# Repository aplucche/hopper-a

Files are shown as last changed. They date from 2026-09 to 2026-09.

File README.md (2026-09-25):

# HOPPER-A — rubber-band jumping toy (42 mm cube, PLA + rubber bands only)

***Note on LLM Usage***: *All code and documentation after this section is fully generated. This is a test of Opus 5.5 with Claude Code for physical design. The unmodified prompt is below (created on mobile so excuse some poor grammar and typos). All development was done in a Claude Code cloud env.*

***One-shot prompt***:
> Can you make an openscad file with all components laid out in a printable manner as well as a toggle-able view of an assembled version for an A1 mini bambu printer. The project: a hopper toy with only PLA and rubber bands that had an easy way to release without getting in the way. must be completely enclosable in 42mm cubed dimensions.  
Goals are jumps n feet in the air with only parts specified and m rubber bands. Can withstand tension of specified number of bands without plastic breaking.  
I will be unavailable so please act autonomously and with as high a quality end result as possible. Autonomously use version control along the way.

**Video of assembled device in action:**

https://github.com/user-attachments/assets/377958ef-da96-43a3-9e8f-0fc779bee860

---
-- Generated --
# HOPPER-A — rubber-band jumping toy (42 mm cube, PLA + rubber bands only)

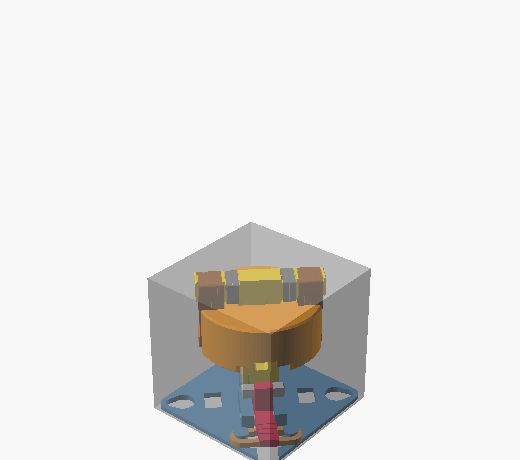
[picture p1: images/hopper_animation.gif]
animation


A 3D-printable jumping toy for the **Bambu Lab A1 mini**. It's made from PLA and standard **#8 rubber bands** and nothing else: no screws, springs or glue.
The whole toy, bands included, fits inside a **42 × 42 × 42 mm cube** (measured: 41.7 × 41.7 × 41.6 mm).

| | 2 bands (1 per side) | **4 bands (2 per side) — recommended** | 6 bands (3 per side) — limit |
|---|---|---|---|
| predicted jump (nominal) | 3.0 ft (0.9 m) | **5.6 ft (1.7 m)** | 8.0 ft (2.4 m) |
| realistic range (soft … stiff bands) | 1.8 – 4.4 ft | **3.5 – 8.1 ft** | 5.1 – 11.4 ft |
| force to cock (push the body down) | 25 N (2.6 kgf) | 50 N (5.2 kgf) | 76 N (7.7 kgf) |
| pedal force to fire | ≈3 N | ≈5 N | ≈7 N |
| lowest static safety factor on the PLA | 6.2 | **3.1** | 2.1 |
| lowest impact safety factor (pessimistic) | 3.5 | **2.5** | 2.0 |

**Goal statement.** With only the printed parts and **4 × #8 rubber bands** (each looped double), the toy jumps
**about 5½ ft (1.7 m) straight up**. Every PLA part keeps a **safety factor of 3 or more** when cocked with those
4 bands, and still **2 or more at 6 bands**. The full numbers are in [docs/PERFORMANCE.md](docs/PERFORMANCE.md).
The jump heights come from a physics model. Real rubber bands vary a lot, so expect your toy to land somewhere in the range column.

Also needed: **1 more #8 band** for the trigger return spring and **2 more** for the crossbar bumpers.
That's **7 × #8 bands** in total for the recommended build.

## How it works

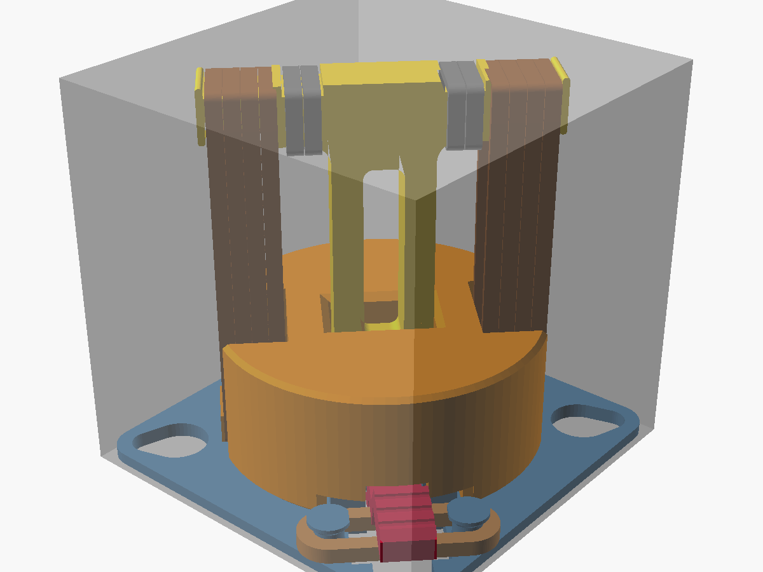
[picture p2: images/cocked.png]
cocked


* **Foot** (blue): the base plate. It holds the central boss and the pivot block.
* **Frame** (gold): a "T" made of a stem and a crossbar. It's printed lying flat, so every tensile load runs along the filament. It pins into the foot from underneath.
* **Body** (orange): a 7.3 g puck that slides on the stem. Its mass is tuned to match the 7.1 g foot side, because a 1:1 split maximises jump height for a given amount of band energy.
* **Bands**: they loop over the crossbar ends and under pegs at the bottom of the body. Pushing the body *down* stretches them to about 3.9× their length.
* **Latch**: a pedal lever sits in the foot. Its steel-grey **sear pin** hooks over two barbs that hang inside the body.
  * **Cocking:** push the body down. The barbs cam the pin aside and it clicks in (18.6 mm stroke).
  * **Firing:** tap the **corner pedal down**. After about 13° of rotation (≈3 mm of pedal travel) the pin slips off the barbs. The body shoots up at about 12 m/s, hits the rubber-cushioned crossbar, and yanks the whole toy off the table.
  * **Why the pedal stays out of the way:**
    * It sits at the foot corner, outside the body's path.
    * You press it *down*, so the toy can't be pushed sideways across the table.
    * After release the lever can keep swinging for another 45°+. A finger still resting on the pedal therefore can't hold the foot down. The foot just pulls the pedal out from under the finger.
  * **Return spring:** a doubled #8 band stretched between two pegs like a bow-string, under the pedal arm.

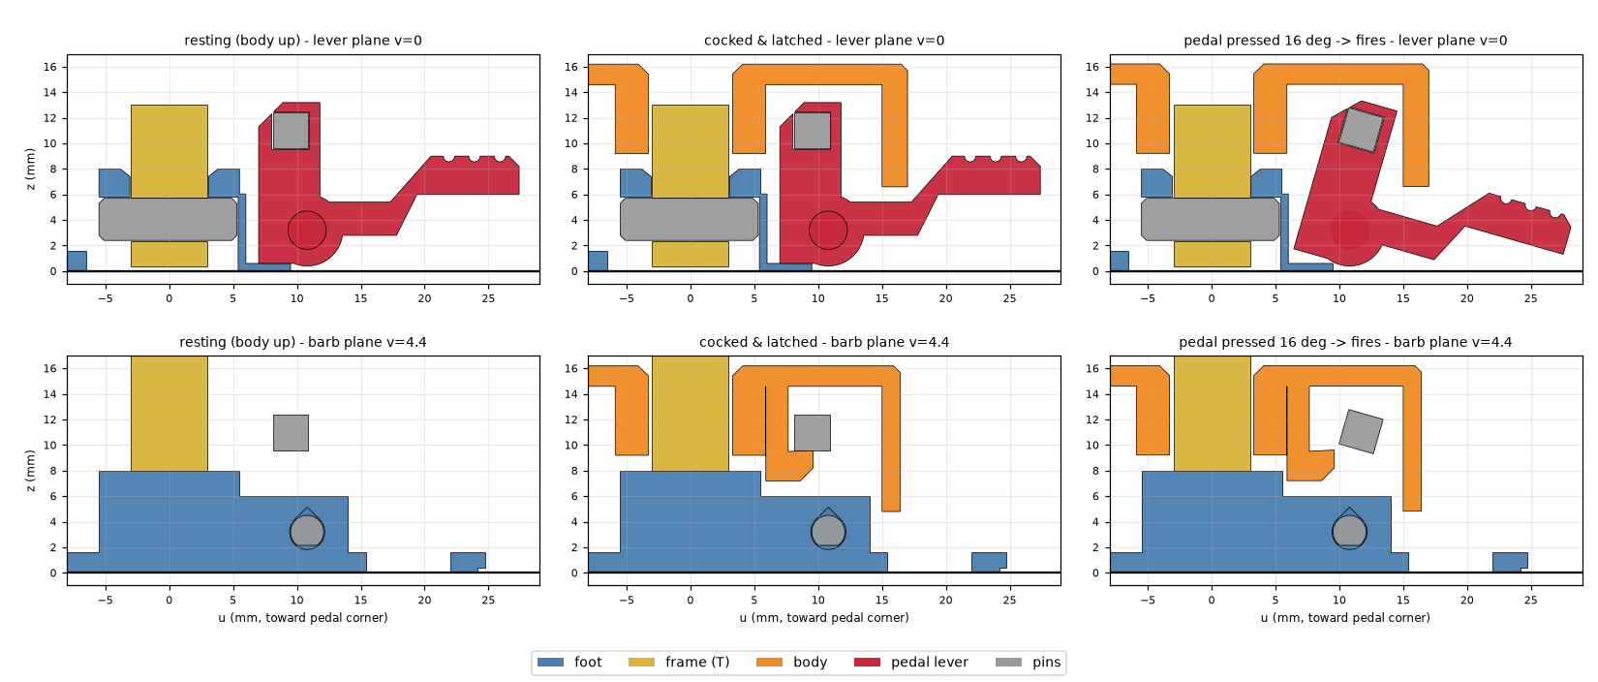
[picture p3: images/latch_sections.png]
latch sections


## Files

| file | what |
|---|---|
| `hopper.scad` | The fully parametric model. Open it in OpenSCAD and use the **Customizer** `view` drop-down to switch between the views below. |
| `stl/hopper_plate.3mf` | **All 10 parts laid out for the A1 mini plate, as separate objects.** Open it directly in Bambu Studio. |
| `stl/hopper_*.stl` | One STL per part, already in print orientation. `hopper_plate.stl` is the whole plate as a single mesh. |
| `docs/PERFORMANCE.md` | Generated report: stretch, forces, energy, jump height, trigger force, and a safety factor for every load path. |
| `docs/BUILD.md` | Printing, assembly, use and tuning. |
| `tools/` | Checks and generators (see below). |

### Views in `hopper.scad` (Customizer → View → `view`)

| `view` | shows |
|---|---|
| `assembled` | resting toy inside the transparent 42 mm envelope cube (default) |
| `cocked` | body pulled down and latched |
| `firing` | pedal pressed and sear released |
| `exploded` | assembly pulled apart vertically |
| `section` | cocked toy cut on the lever mid-plane |
| `animate` | cock → fire → jump; use View ▸ Animate (FPS 15, Steps 120) |
| `print` | every part on the 180 × 180 A1 mini bed |
| `part` | one part (choose it in `part`) in print orientation, for STL export |

Other toggles: `show_bands`, `show_envelope`, `show_bed`, `bands_per_side` (1–3, visual only).
Print fits (`fit_slide`, `fit_rot`, `fit_pin`) and latch tuning (`e_bias`, `barb_tilt`, `overtravel`) are Customizer parameters too.

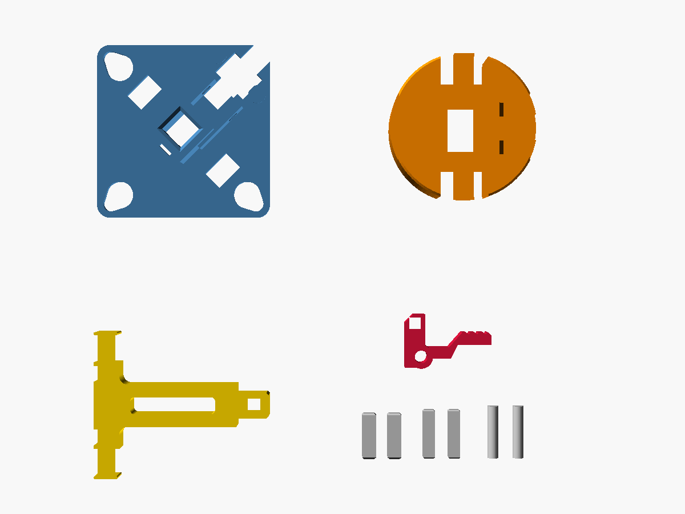
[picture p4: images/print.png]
print plate


## Verification (`tools/build_all.sh`)

The tools rebuild and re-check everything after any edit:

* **`check_geometry.py`** runs exact mesh booleans (manifold3d) on every part and checks:
  * every part is a closed solid
  * no two parts overlap at rest, latched or bottomed out
  * the latch cocks correctly at every body height, and the lever deflection needed on the way down is recorded
  * the sear releases at 13° of rotation
  * the lever swings freely for at least 45° after release
  * the assembled toy, bands included, fits inside 42 mm
  * the body's centre of mass sits on the stem axis (0.13 mm off)
  * it also records each part's mass
* **`hopper_calc.py`** runs the neo-Hookean rubber model, the launch and drag model, the trigger and friction model, and the stress checks. It writes `docs/PERFORMANCE.md`.
* **`section_plot.py`** draws the latch cross-sections from the real meshes.
* **`export_stl.py`** writes the STLs and the 3MF, then checks that the plate holds 10 separate bodies, all on the bed and all inside 180 mm.

Requirements: `openscad` (2021.01 or newer), `xvfb-run` for images, and Python 3 with `trimesh manifold3d shapely scipy matplotlib lxml`.

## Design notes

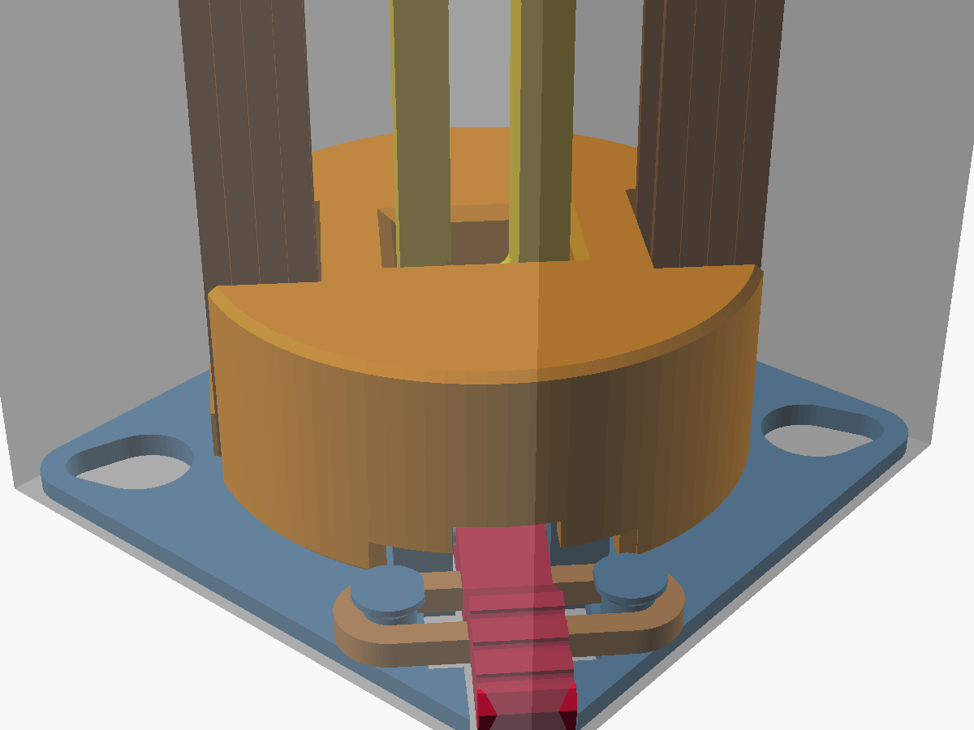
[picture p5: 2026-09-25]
images/firing.png

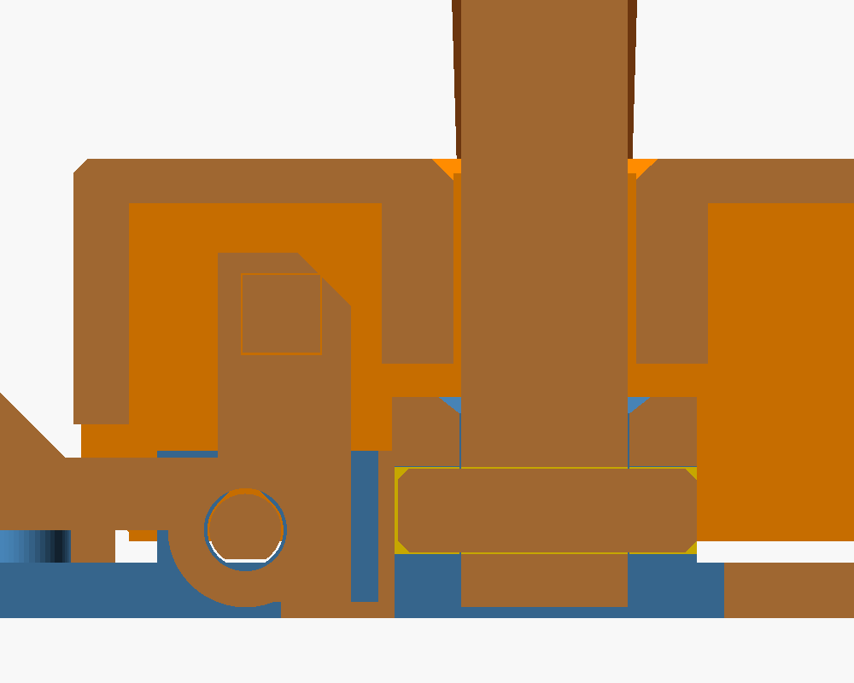
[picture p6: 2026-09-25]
images/section.png

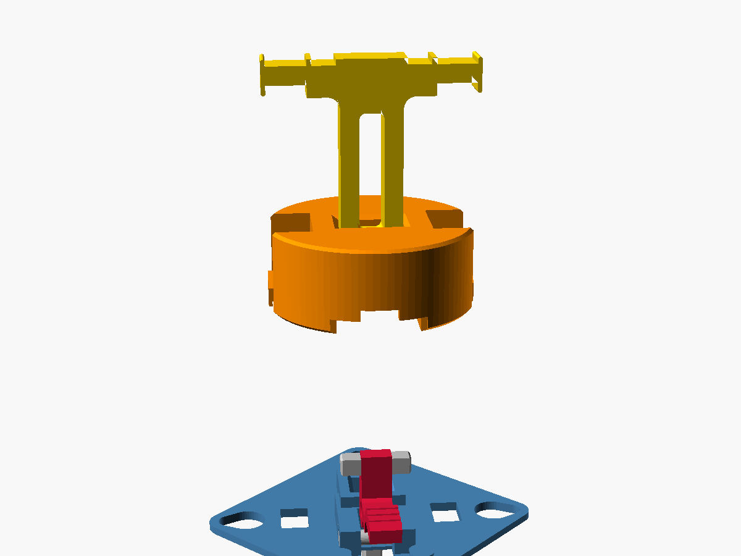
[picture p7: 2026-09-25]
images/exploded.png

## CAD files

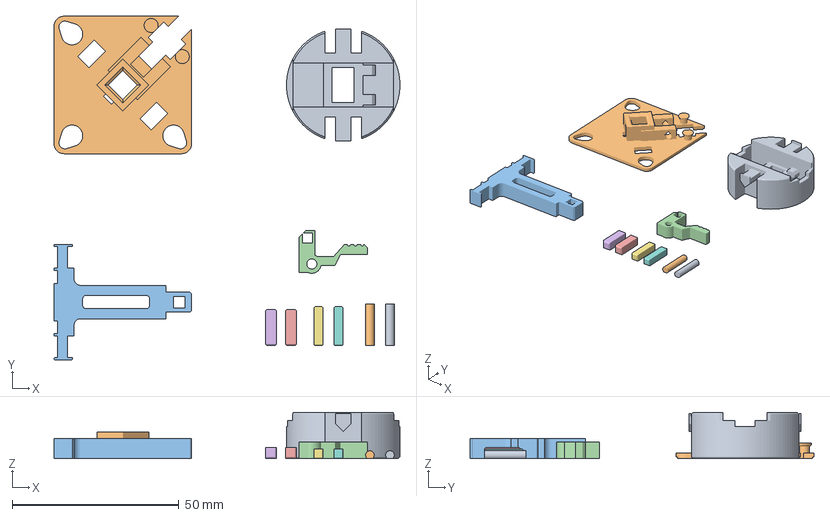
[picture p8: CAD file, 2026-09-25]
stl/hopper_plate.3mf
103.6 x 102.9 x 13.8 mm

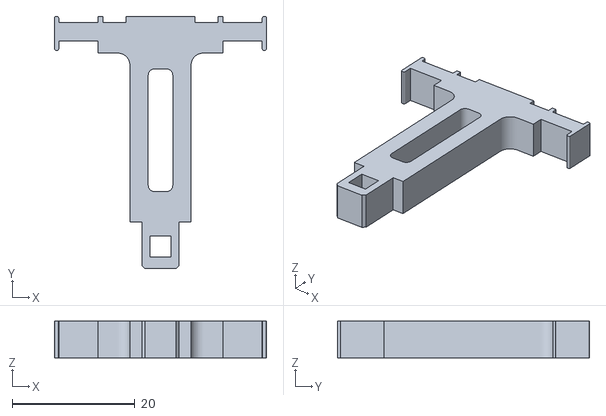
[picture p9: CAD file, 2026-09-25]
stl/hopper_frame.stl
34.6 x 41.2 x 6.00

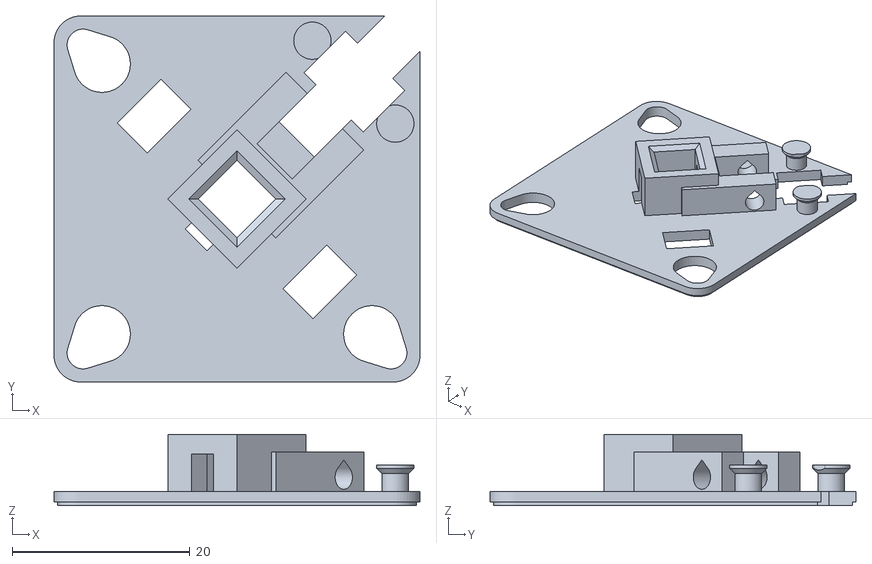
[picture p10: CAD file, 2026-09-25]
stl/hopper_foot.stl
41.2 x 41.2 x 8.00

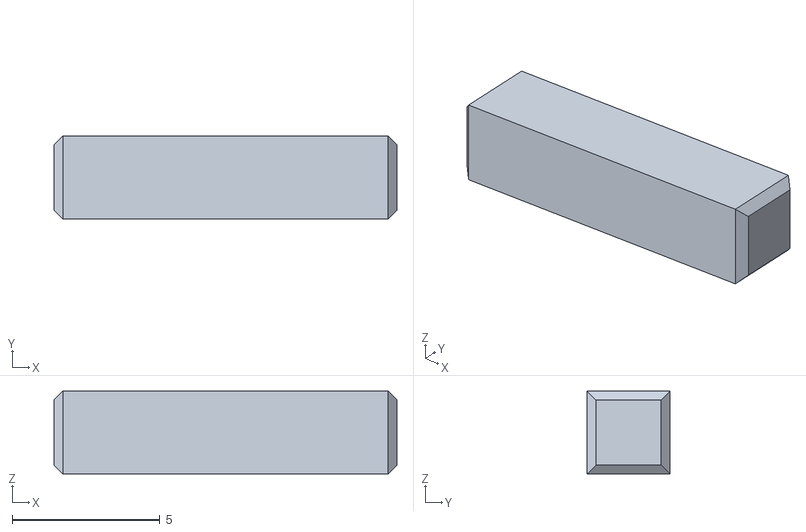
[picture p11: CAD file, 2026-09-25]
stl/hopper_sear_pin.stl
11.6 x 2.80 x 2.80

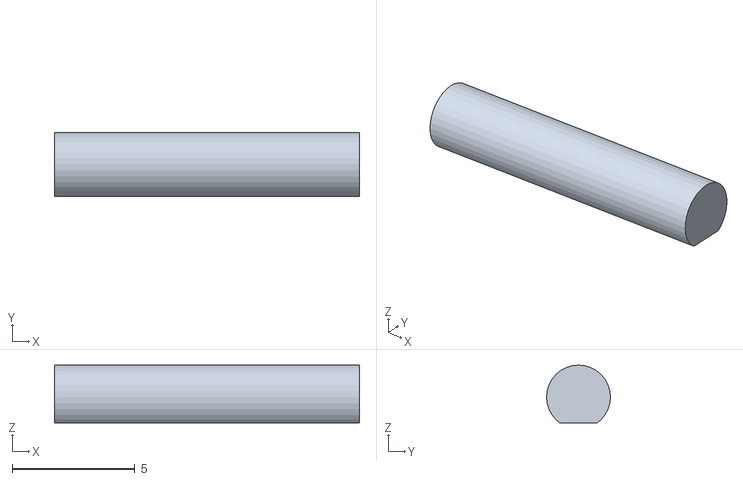
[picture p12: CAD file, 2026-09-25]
stl/hopper_pivot_pin.stl
12.4 x 2.60 x 2.35

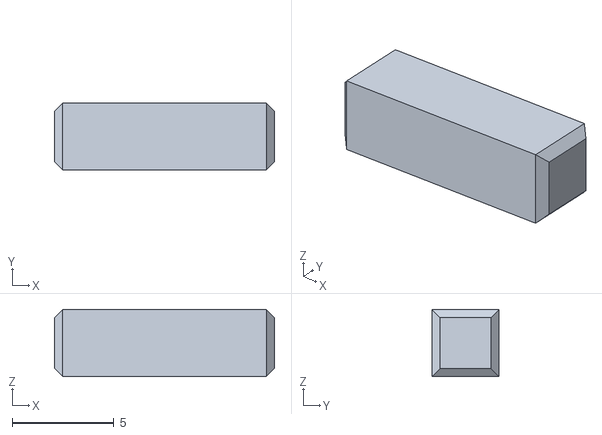
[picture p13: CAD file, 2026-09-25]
stl/hopper_stem_pin.stl
10.8 x 3.30 x 3.30

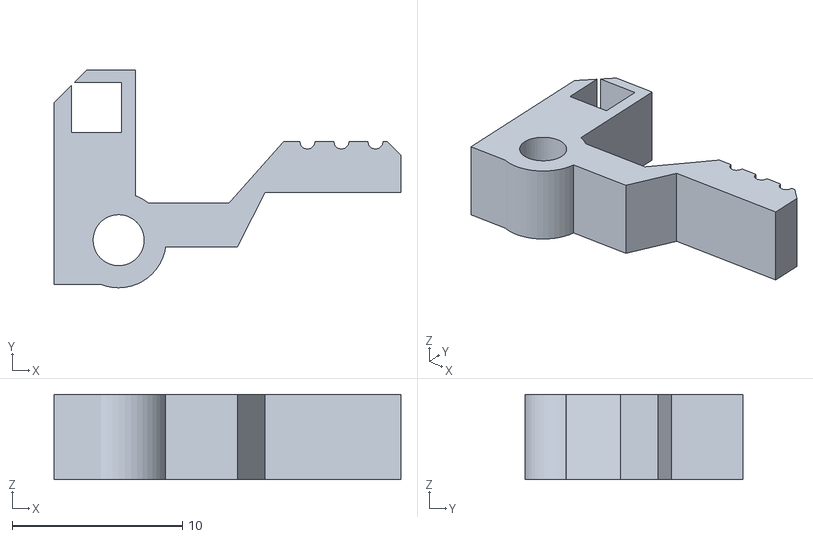
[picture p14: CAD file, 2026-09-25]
stl/hopper_lever.stl
20.4 x 12.8 x 5.00

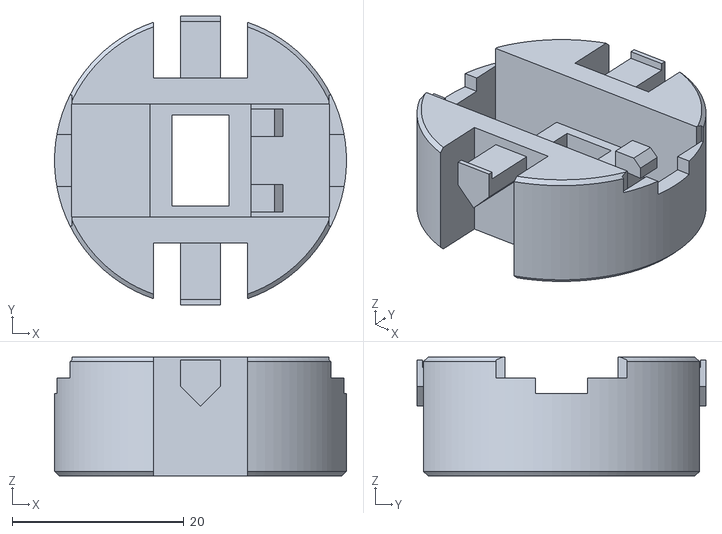
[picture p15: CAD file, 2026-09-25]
stl/hopper_body.stl
34.0 x 33.6 x 13.8

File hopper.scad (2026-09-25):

// =====================================================================
//  HOPPER-A  :  rubber-band jumping toy, 42 mm cube envelope
//  PLA + standard #8 rubber bands only.  Designed for Bambu Lab A1 mini.
//
//  How it works
//  ------------
//  * FOOT  : a base plate with a central boss and a pivot block.
//  * FRAME : a "T" (stem + crossbar) pinned into the foot. Printed lying
//            flat so every tensile load runs along the filament.
//  * BODY  : a heavy puck that slides on the stem.
//  * BANDS : loop over the crossbar ends and under pegs at the bottom of
//            the body, so pushing the body DOWN stretches them.
//  * LATCH : a pedal lever in the foot. Its sear pin hooks over two barbs
//            on the body. Push the body down -> it clicks. Tap the corner
//            pedal DOWN -> the pin slips off the barbs -> the body shoots up,
//            slams the crossbar and yanks the whole toy into the air.
//            The pedal is at the corner, outside the body's path, and the
//            lever keeps rotating freely after release, so a finger on
//            the pedal cannot hold the foot down.
//
//  Views (Customizer "view"):
//    assembled  - resting state (bands relaxed)          [default]
//    cocked     - body pulled down and latched
//    firing     - pedal pressed, sear released
//    exploded   - assembly exploded along Z
//    section    - cocked state cut on the lever mid-plane
//    animate    - use View > Animate (FPS 15, Steps 120)
//    print      - all parts laid out on the 180x180 A1-mini plate
//    part       - a single part (set "part") in print orientation
//
//  Units: mm. Mechanism frame: X = lever axis (u), Y = crossbar axis (v).
//  The assembled views are rotated -45 deg so the square foot is aligned
//  with the world axes and the 42 mm envelope cube.
// =====================================================================

/* [View] */
view = "assembled"; // [assembled, cocked, firing, exploded, section, animate, print, part, info]
part = "foot";      // [foot, body, frame, lever, stem_pin, pivot_pin, sear_pin]
show_bands = true;
show_envelope = true;
show_bed = true;
bands_per_side = 2; // [1, 2, 3]

/* [Fit tuning (mm)] */
fit_slide = 0.30;   // body bore clearance per side on the stem
fit_rot   = 0.40;   // diametral clearance of lever on pivot pin
fit_pin   = 0.15;   // diametral clearance for press-in pins (holes are +this)
fit_gap   = 0.40;   // general non-contact clearance

/* [Latch tuning] */
e_bias    = 1.2;    // pivot offset beyond barb edge; bigger = lighter trigger
barb_tilt = 3;      // deg; barb face rises toward the lever (adds hold)
overtravel = 0.8;   // how far past the latch point the body must be pushed

/* [Hidden] */
$fn = 48;
eps = 0.01;

// ---------------- envelope ----------------
env        = 42;
env_margin = 0.4;
top_z      = env - env_margin;          // 41.6 top of crossbar
foot_side  = env - 2*env_margin;        // 41.2 square foot
foot_cr    = 3;                         // foot corner radius

// ---------------- foot ----------------
t_plate  = 1.6;
boss_h   = 5.5;      // half size of central boss
boss_top = 8.0;
ten_h    = 3.0;      // tenon half size (u & v)
ten_z0   = 0.4;
spin     = 3.3;      // stem pin section (square)
spin_z0  = 2.4;
spin_u0  = -boss_h;  // pin runs from here...
spin_len = 10.8;     // ...for this long (+u end stops in the groove)

// ---------------- lever / pivot ----------------
pv_d       = 2.6;                         // pivot pin diameter
lev_boss_r = (pv_d + fit_rot)/2 + 1.3;
lev_min_z  = 0.4;
z_p        = lev_min_z + lev_boss_r;      // pivot height
blk_top    = z_p + (pv_d + fit_pin)/2*sqrt(2) + 0.9;  // teardrop apex + wall
blk_v      = 6.2;                         // pivot block half width
blk_u1     = 14.0;                        // pivot block end
slot_v     = 2.8;                         // lever slot half width
lw         = 5.0;                         // lever thickness
slot_u0    = 6.0;
slot_floor_z  = 0.6;                      // lever rest stop (tail sits here)
slot_floor_u1 = 9.5;

// ---------------- sear geometry ----------------
z_b_min   = t_plate;                      // body bottoms on the plate
z_b_latch = z_b_min + overtravel;
prong_u0  = boss_h + fit_gap;             // 5.9
prong_v0  = slot_v;                       // 2.8
prong_v1  = 6.0;
pr_bot_rel   = blk_top + 0.35 - z_b_min;  // prong bottom above body bottom
barb_h       = 2.4;
barb_top_rel = pr_bot_rel + barb_h;       // barb edge height (body frame)
u_f       = 9.6;                          // barb +u face
ov        = 1.5;                          // sear overlap
sear_clr  = 0.45;
step_u    = u_f - ov - sear_clr;          // prong face above the barb
z_c       = z_b_latch + barb_top_rel;     // contact height when latched
u_p       = u_f + e_bias;                 // pivot position
lp        = 2.8;                          // sear pin section (square)
lp_u0     = u_f - ov;                     // sear pin -u face
lp_len    = 2*(prong_v1 - 0.2);           // 11.6
head_wall = 0.8;
head_u0   = lp_u0 - head_wall;
head_u1   = lp_u0 + lp + head_wall;
head_top  = z_c + lp + head_wall;
tail_u0   = 7.0;
tooth_u1  = head_u1 + 0.1;

// bow-string return spring (one #8 band doubled round two pegs)
peg_u  = 18.6;
peg_v  = 6.6;
peg_r  = 1.5;
bs_h   = 1.6;                             // band width (stands on edge)
arm_z0 = t_plate + bs_h - 0.4;            // arm rests 0.4 into the band
arm_z1 = arm_z0 + 2.6;
arm_u1 = 17.8;
pad_u0 = 20.5;
pad_u1 = 27.4;
pad_z0 = 6.0;
pad_z1 = 9.0;
win_u0 = 15.4;  win_u1 = 22.0;  win_v = 4.7;   // window under the bow-string

// ---------------- frame (T) ----------------
stem_u  = 6;          // = print thickness of the frame
stem_v  = 5;          // half width of stem
stem_win = [2.0, 13.0, 33.0];   // lightening window in the stem: half width, z0, z1
cb_mid_z0 = top_z - 6;          // 35.6 (deep: takes the landing blow)
cb_mid_v  = 10.2;
cb_end_z0 = 37.6;
cb_end_z1 = 40.6;               // bands on top stay below top_z
cb_end_v  = 16.6;
knob_w    = 0.7;
bump_v0 = 5.6;  bump_v1 = 9.4;  bump_rec = 1.0;   // bumper band grooves
bump_t  = 0.8;                                     // bumper rubber thickness

// ---------------- body ----------------
R_b     = 17.0;
d3      = 12.2;                               // deep sear pocket
H_b     = d3 + 1.6;                           // 13.8
z_b_rest = cb_mid_z0 - bump_t - H_b;          // body bottom at rest
stroke  = z_b_rest - z_b_latch;
slot_u  = 5.5;                                // band slot half width
slot_v0 = 9.6;                                // band slot floor
pk_v    = 6.6;                                // pocket half width
d1      = boss_top - t_plate + fit_gap;       // boss pocket depth
p3_u1   = 15.0;
d4      = arm_z1 + fit_gap - t_plate;         // arm channel depth
p4_u0   = 11.0;
p4_v    = slot_v + 0.2;
bpeg_z0 = 1.2;  bpeg_z1 = 3.4;  bpeg_u = 2.3;  // body band peg
bpeg_v1 = 16.2; bknob = 0.6;

// ---------------- sanity checks ----------------
assert(pr_bot_rel + z_b_min >= blk_top + 0.3, "prongs hit pivot block");
assert(head_top + fit_gap <= z_b_min + d3,     "lever head hits body pocket");
assert(stroke > 15, "stroke too short");
assert(R_b <= env/2 - env_margin, "body outside envelope");

// =====================================================================
//  helpers
// =====================================================================
module rsq(s, r) offset(r=r) offset(delta=-r) square(s, center=true);

module teardrop_y(d, len) {           // hole along Y, printable (tip up)
    rotate([90,0,0]) linear_extrude(len, center=true) {
        circle(d=d);
        rotate(45) square(d/2);
    }
}

module box(p0, p1) translate(p0) cube([p1[0]-p0[0], p1[1]-p0[1], p1[2]-p0[2]]);

// extrude a 2D (u,z) profile across v (centered)
module uz_extrude(w) rotate([90,0,0]) linear_extrude(w, center=true) children();

// =====================================================================
//  FOOT
// =====================================================================
module foot_2d() rotate(45) rsq(foot_side, foot_cr);

module bs_peg() {
    cylinder(r=peg_r, h=bs_h + 0.4 + eps);                           // shank
    translate([0,0,bs_h + 0.4]) cylinder(r1=peg_r, r2=peg_r+0.6, h=0.6);
    translate([0,0,bs_h + 1.0]) cylinder(r=peg_r+0.6, h=0.4);
}
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

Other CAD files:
stl/hopper_plate.stl

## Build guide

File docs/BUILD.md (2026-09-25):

# Build guide

## 1. Print (Bambu Lab A1 mini, PLA)

Open `stl/hopper_plate.3mf` in Bambu Studio. Every part is already laid out in its print orientation.

| setting | value | why |
|---|---|---|
| material | PLA | |
| layer height | 0.20 mm (0.16 mm if you want smoother pins) | |
| walls | 3 | |
| **infill** | **100 %** | The strength numbers assume it. The body/foot mass split (7.3 g / 7.1 g) is tuned for it too. |
| supports | **none** | Everything is designed to print without them. |
| brim | optional, 3 mm on the pins | |
| elephant-foot compensation | 0.1–0.15 mm | Keeps the slots and holes true. |

Print orientations, all already set in the files:

* **foot**: flat. The pivot holes are teardrops, so they bridge cleanly.
* **frame**: lying flat. This is essential, because the stem and crossbar work in tension along the filament.
* **body**: upside down. The pockets open upward and the band pegs have 45° roofs.
* **lever**: flat.
* **pins**: lying down. Two spares of each are included, since they are tiny and easy to lose.

## 2. You need

**7 × #8 rubber bands** (7/8" × 1/16"):

* 4 main bands
* 1 trigger return band
* 2 bumper bands

Fewer or more main bands also work; see the table in the README. For the main bands, **only #8 bands looped double have been modelled**.

## 3. Assemble (about 5 minutes)

1. **Lever**
   1. Drop the red pedal lever into the slot in the foot. The tall tooth goes toward the centre and the pad goes toward the cut-out corner.
   2. Push the round **pivot pin** in from the side, through the pivot block and the lever, until it is flush on both sides.
   3. Check that the lever swings freely. If it doesn't, ream the lever hole with a 3 mm drill bit by hand.
2. **Sear pin**: press the 2.8 mm square pin into the square hole at the top of the lever tooth. Centre it so it sticks out the same amount on each side.
3. **Return band ("bow-string")**
   1. Loop one #8 band doubled (twist it into an 8 and fold it) around the two mushroom pegs next to the pedal.
   2. Make sure it passes *under* the pedal arm, closest to the pivot.
   3. Check: the pedal should now spring back up by itself when pressed.
4. **Bumpers**: wrap one #8 band 2–3 turns around each of the two grooves on top of the crossbar. The rubber under the crossbar is what the body hits.
5. **Body onto the frame**
   1. Look into the bottom of the orange body and find the two small hanging **barbs**.
   2. Slide the body onto the stem from the stem's *bottom* end, with the barbs on the pedal side.
6. **Frame into the foot**
   1. Push the square tenon on the bottom of the stem into the square socket in the foot.
   2. Lift the body out of the way, then push the square **stem pin** through the tenon from the side *opposite* the pedal. It slides along the groove under the boss until it is flush.
   3. The pin is what stops the frame pulling out of the foot on every jump.
7. **Main bands**
   1. Twist each band into an 8 and fold it into a double loop.
   2. Hook it over one crossbar end.
   3. Stretch it down the body's side slot and hook it *under* the peg at the bottom of the slot.
   4. Put **the same number of bands on each side**. Uneven bands tip the body on the stem and waste energy.

## 4. Use

1. **Cock it**
   1. Stand the toy on a table.
   2. Straddle the crossbar with two fingers and push the body straight down until it **clicks**. This takes 50 N with 4 bands, a firm push.
   3. Let go slowly: the body rises 0.8 mm and seats on the latch.
2. **Fire it**
   1. Put it down, clear of your face.
   2. **Tap the corner pedal downward** with a fingertip or fingernail and take your finger straight off.
   3. The toy fires after about 3 mm of pedal travel.
3. **Safety**
   * Never cock it pointing at anyone's face, and keep eyes above the table plane.
   * Don't leave it cocked, and unhook the main bands for storage. The permanent pull makes PLA creep, especially somewhere warm like a car.
   * Replace bands as soon as they show cracks.
   * **Never exceed 6 main bands.**

## 5. Tuning (all Customizer parameters in `hopper.scad`)

| symptom | fix |
|---|---|
| pedal too stiff | raise `e_bias` by 0.2 mm (default 1.2) |
| fires by itself after cocking | lower `e_bias` by 0.2 mm, or raise `barb_tilt` |
| pins fall out / won't go in | `fit_pin` −0.05 / +0.05 |
| body binds on the stem | `fit_slide` +0.05 |
| lever stiff on its pivot | `fit_rot` +0.1 |

After changing parameters, run `tools/build_all.sh` to re-check the geometry and re-export the print files.

## 6. Calibrating the prediction to your bands

Rubber band stiffness varies about ±40 % between brands, and that is where most of the uncertainty in the jump height comes from. To calibrate:

1. Loop one band double over two pencils. Hang a known mass (for example a 500 g water bottle) from the lower pencil.
2. Measure the centre-to-centre gap between the pencils.
3. Run

   ```
   python3 -c "import sys; sys.path.insert(0,'tools'); from hopper_calc import calibrate_band; print(calibrate_band(MASS_G, GAP_MM))"
   ```

4. Put the resulting `G` (MPa) into `G_NOM` in `tools/hopper_calc.py`.

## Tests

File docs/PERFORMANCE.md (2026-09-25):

# HOPPER-A performance and strength report

_Generated by `tools/hopper_calc.py` from the current `hopper.scad` geometry. Do not edit by hand._

## Geometry
* stroke 18.6 mm, body rest z = 21.0 mm, latched z = 2.4 mm
* main-band stretch (#8 doubled): rest lambda = 2.25, latched lambda = 3.92
* masses at 100 % infill: body 7.28 g, foot side 7.11 g (frame, foot, lever, pins), bands 0.05 g each

## Predicted performance (#8 bands, each looped double)

| bands | per side | latch force | stored energy | body speed | take-off | jump height (nominal) | range (soft..stiff bands) | pedal force |
|---|---|---|---|---|---|---|---|---|
| 2 | 1 | 25.3 N | 0.362 J | 8.6 m/s | 4.33 m/s | **0.90 m = 3.0 ft** | 1.8 - 4.4 ft | 3.1 N |
| 4 | 2 | 50.5 N | 0.723 J | 12.2 m/s | 6.11 m/s | **1.71 m = 5.6 ft** | 3.5 - 8.1 ft | 5.1 N |
| 6 | 3 | 75.8 N | 1.085 J | 14.9 m/s | 7.47 m/s | **2.44 m = 8.0 ft** | 5.1 - 11.4 ft | 7.1 N |

Assumptions: G = 0.65 MPa (range 0.45-0.9), energy return 80% (range 70%-88%), 5% guide/bumper loss, air drag Cd 1.05 on 1450 mm^2. Height is the rise of the toy's centre of mass.

## Trigger
* 2 bands: pedal force 3.1 N at mu=0.30 (1.9 N at mu=0.20, 4.9 N at mu=0.45); latch holds for any friction coefficient above 0.11
* 4 bands: pedal force 5.1 N at mu=0.30 (2.6 N at mu=0.20, 8.8 N at mu=0.45); latch holds for any friction coefficient above 0.12
* 6 bands: pedal force 7.1 N at mu=0.30 (3.4 N at mu=0.20, 12.7 N at mu=0.45); latch holds for any friction coefficient above 0.13
* bow-string return spring: 3.8 N mm holding torque at rest, 13.9 N mm at the release angle; pedal lever arm 13.1 mm

## Strength (100 % infill PLA, conservative strengths)

### 4 bands (latch load 50.5 N)

| feature | stress | strength | safety factor | note |
|---|---|---|---|---|
| sear pin bending | 13.1 MPa | 50 MPa | 3.8 | printed lying: along filament |
| barb ledge bending | 16.0 MPa | 50 MPa | 3.1 | stress in layer plane |
| prong tension | 4.5 MPa | 20 MPa | 4.4 | across layers |
| pivot pin shear | 4.8 MPa | 30 MPa | 6.3 | printed lying |
| pivot block tear-out | 3.7 MPa | 15 MPa | 4.1 | teardrop roof, across layers |
| crossbar end bending | 9.0 MPa | 50 MPa | 5.6 | frame printed flat |
| body peg bending | 13.0 MPa | 50 MPa | 3.9 | horizontal cantilever |
| stem bending (latched) | 13.5 MPa | 50 MPa | 3.7 | frame printed flat |
| stem shoulder bearing | 2.1 MPa | 50 MPa | 23.8 |  |

### 6 bands (latch load 75.8 N)

| feature | stress | strength | safety factor | note |
|---|---|---|---|---|
| sear pin bending | 19.7 MPa | 50 MPa | 2.5 | printed lying: along filament |
| barb ledge bending | 24.0 MPa | 50 MPa | 2.1 | stress in layer plane |
| prong tension | 6.8 MPa | 20 MPa | 3.0 | across layers |
| pivot pin shear | 7.1 MPa | 30 MPa | 4.2 | printed lying |
| pivot block tear-out | 5.5 MPa | 15 MPa | 2.7 | teardrop roof, across layers |
| crossbar end bending | 13.5 MPa | 50 MPa | 3.7 | frame printed flat |
| body peg bending | 19.4 MPa | 50 MPa | 2.6 | horizontal cantilever |
| stem bending (latched) | 20.2 MPa | 50 MPa | 2.5 | frame printed flat |
| stem shoulder bearing | 3.2 MPa | 50 MPa | 15.8 |  |

## Impact (body hitting the crossbar)

Rough, deliberately pessimistic: the blow is assumed to last only 0.1 ms and PLA's higher strength under short impacts is ignored.

| bands | impact speed | energy lost in the collision | taken by bumper bands | PLA contact stress | crossbar bending | stem tension | stem-pin shear | lowest SF |
|---|---|---|---|---|---|---|---|---|
| 2 | 8.6 m/s | 135 mJ | 50 mJ | 7.2 MPa | 12.5 MPa | 8.5 MPa | 8.5 MPa | 3.5 |
| 4 | 12.2 m/s | 268 mJ | 50 mJ | 11.6 MPa | 20.1 MPa | 12.1 MPa | 12.0 MPa | 2.5 |
| 6 | 14.9 m/s | 401 mJ | 50 mJ | 14.7 MPa | 25.5 MPa | 14.8 MPa | 14.7 MPa | 2.0 |

## Resting preload (creep)
* 2 bands: 13.4 N permanently pulls the body onto the bumpers; worst resting stress 3.4 MPa (body pegs). PLA creeps noticeably above ~10 MPa when warm, so unhook the bands for storage.
* 4 bands: 26.8 N permanently pulls the body onto the bumpers; worst resting stress 6.9 MPa (body pegs). PLA creeps noticeably above ~10 MPa when warm, so unhook the bands for storage.
* 6 bands: 40.3 N permanently pulls the body onto the bumpers; worst resting stress 10.3 MPa (body pegs). PLA creeps noticeably above ~10 MPa when warm, so unhook the bands for storage.

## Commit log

2026-09-25 Add parametric hopper toy model with pedal-release latch and geometry checker
    Claude-Session: https://claude.ai/code/session_01WeXp8TTHJRENhetMNxQM28
    [hopper.scad]
2026-09-25 Add performance/strength calculator, latch section plots; strengthen pegs, crossbar and stem pin
    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
    [hopper.scad]
2026-09-25 Add print files (STL + A1 mini 3MF plate), renders, animation, build guide and README
    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
    [hopper_body.stl, hopper_foot.stl, hopper_frame.stl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]
